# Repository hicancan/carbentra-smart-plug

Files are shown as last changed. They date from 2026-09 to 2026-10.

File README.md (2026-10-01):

<div align="center">

> 2026-10-01 classroom upgrade: the sole multi-device Edge and contract authority moved to `carbentra-campus-platform/edge` and `packages/iot-contract`. This repository owns Plug hardware, firmware and physical qualification facts. New local ON uses the same commissioning/load/feedback/dwell guards; actual presses establish a15-minute manual hold. The default target still disables actuation. Historical broker/PDF evidence does not automatically validate upgraded shared sources.

# CARBENTRA Plug

### 面向校园能源编排的 AIoT 边缘智能插座

**让普通用电设备拥有可感知、可判断、可执行、可验证的能源接口。**

[English](README_EN.md) ·
[机械工程](mechanical/rev_b/) ·
[电气工程](electronics/rev_b/integrated/) ·
[固件](firmware/) ·
[边缘服务](edge/) ·
[发布证据](release/)







</div>

本机数字验证与源码摘要见 [交付入口](release/START_HERE.md)。GitHub 徽章展示远端工作流状态；物理放行条件独立保留。

<p align="center">
  <a href="visuals/rev_b/renders/01_hero_ivory.png">
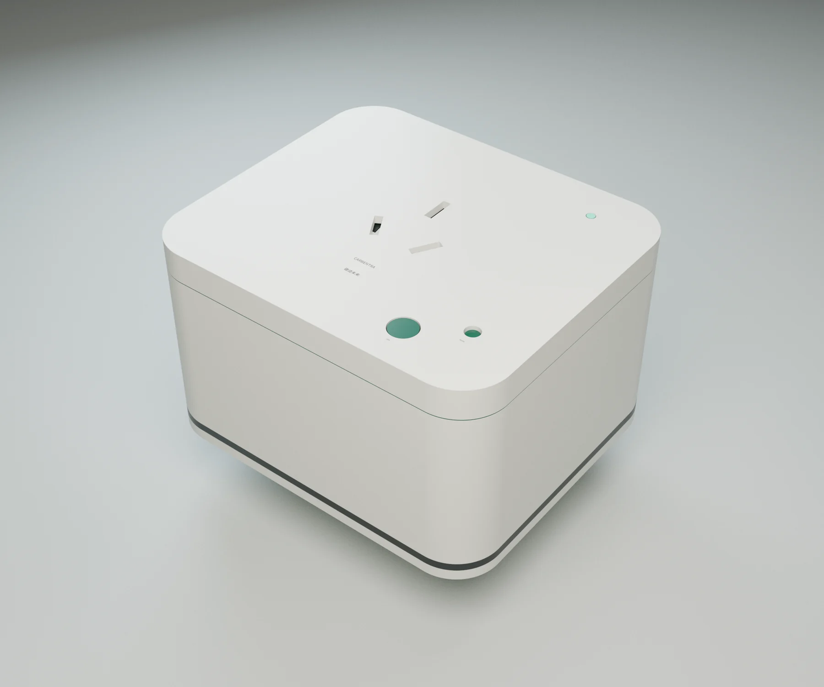
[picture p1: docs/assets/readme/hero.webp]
CARBENTRA Plug Rev B
    
  </a>
</p>

<p align="center">
  <sub>CARBENTRA Plug Rev B · 本地数字验证快照 · 实物尚未验证</sub>
</p>

---

## 一只插座，让普通负载进入可编排能源系统

CARBENTRA Plug 是 CARBENTRA 产品体系的第一个设备终端。

它把传统电器接入一条完整的设备级闭环：

> **感知 → 校验 → 判断 → 执行 → 验证 → 回传**

电压、电流、功率、能量与温度构成设备状态；本地策略决定动作是否具备执行条件；输出反馈确认物理结果；边缘侧持久运输这些事实，平台统一完成资产绑定、预测、约束策略和能碳核算。

当一台设备接入 CARBENTRA Plug，它同时获得联网能力、可观测状态、受约束执行能力，以及一个能够被上层能源系统持续理解的数字接口。

### 四项核心能力

| 能力 | 设备侧职责 |
| --- | --- |
| **感知** | 采集电压、电流、功率、能量、板温与输出状态 |
| **保护** | 本地故障、负载档案、命令时效、序列和物理边界共同参与决策 |
| **执行** | 在本地许可通过后完成受控开关动作 |
| **验证** | 独立读取输出侧状态，把真实结果送回下一轮控制 |

**云端负责全局智能，设备守住物理边界。**

---

## 产品一览

| 项目 | Rev B 数字工程基线 |
| --- | --- |
| 产品名称 | **CARBENTRA Plug** |
| 工程型号 | **CARBENTRA-P16-EVT-B** |
| 名义外形 | **108 × 93 × 65 mm** |
| 主 PCB | **100 × 85 mm，四层** |
| 主控 | **ESP32-C3-WROOM-02U** |
| 电能计量 | **ATM90E26 + 隔离 SPI + 1 mΩ 四端分流器** |
| 机械系统 | **71 个物理机械零件** |
| 主板电气项 | **101 个电气项 + 4 个安装位** |
| 网络链路 | **Wi-Fi + MQTT 双向 TLS** 参考实现 |
| 目标接口 | **单路 220 VAC / 16 A 级设计目标** |
| 当前阶段 | **Rev B 数字工程完成，进入实物 EVT（工程验证样机）前验证阶段** |

<p align="center">
  <a href="visuals/rev_b/renders/02_hero_detail.png">
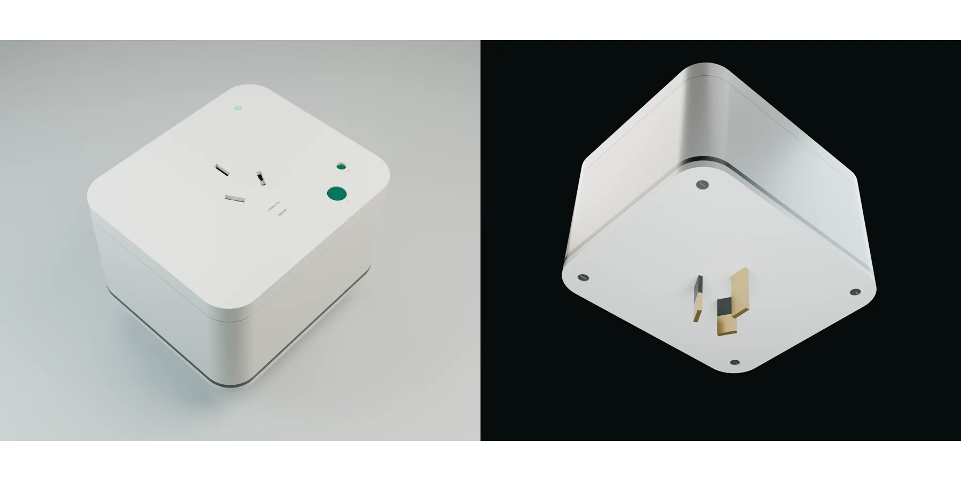
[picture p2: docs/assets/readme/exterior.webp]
CARBENTRA Plug 外观与背部接口
    
  </a>
</p>

外壳、插孔、后部插脚、本地按钮、状态指示、主板空间、保护器件与温度拾取结构都建立在同一套工程坐标系中，并贯通 FreeCAD、KiCad、Blender 与系统装配导出。

---

# 01 · 机械系统 — 让产品在真实空间里成立

Rev B 机械工程覆盖插接结构、保护门、L/N/PE 导电路径、保险与热保护安装、PCB、远端温度拾取、后部插脚和外壳装配。

## 六视图

<a href="visuals/rev_b/renders/07_six_view_sheet.png">
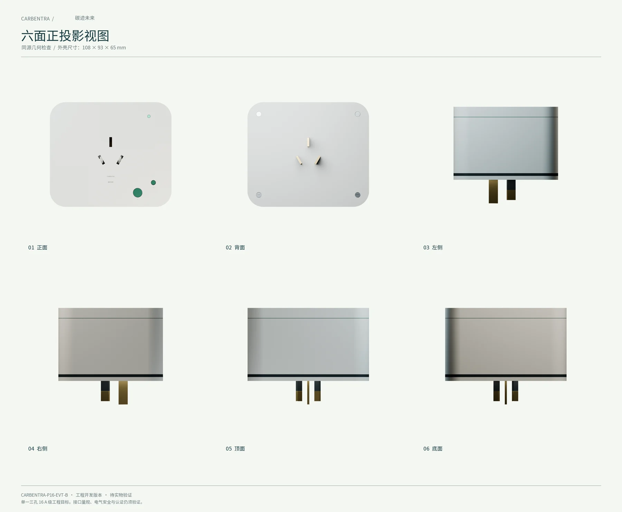
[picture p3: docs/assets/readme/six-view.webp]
CARBENTRA Plug 六视图
  
</a>

六视图给出产品的完整外形关系。当前工程同时提供可编辑 FreeCAD 源、STEP 总装、独立零件、公共坐标系网格、装配边界和机构检查记录。

## 爆炸结构

<a href="visuals/rev_b/renders/06_exploded_annotated.png">
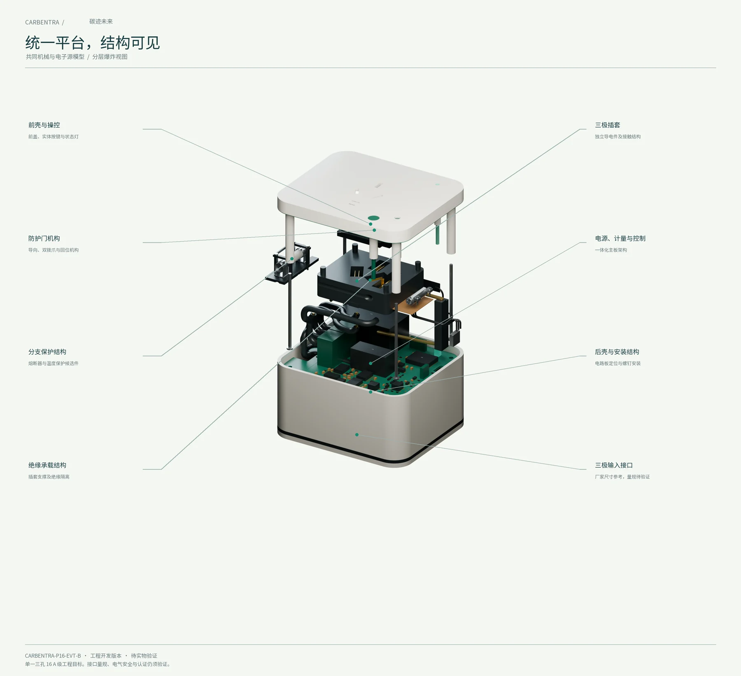
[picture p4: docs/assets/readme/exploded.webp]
CARBENTRA Plug 爆炸结构图
  
</a>

从外到内依次可以看到：

- 前后壳体与装配结构；
- 插孔保护门与接触机构；
- L / N / PE 导电路径；
- 保险与热保护部件；
- 四层主 PCB；
- 远端温度拾取头；
- 后部插脚与内部端接。

### 6 秒爆炸动画

<a href="visuals/rev_b/animation/carbentra_exploded.mp4">
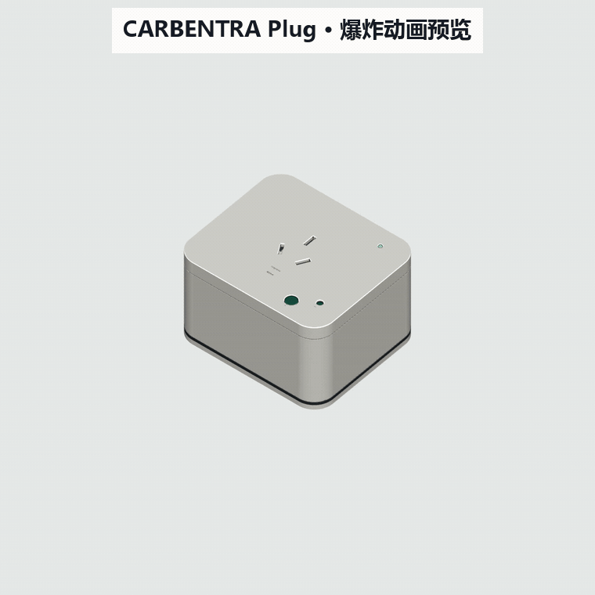
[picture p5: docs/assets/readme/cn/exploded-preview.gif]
CARBENTRA Plug 爆炸动画预览
  
</a>

<p align="center"><sub>点击动画预览可打开原始 MP4。</sub></p>

## 剖视图

<a href="visuals/rev_b/renders/08_section_annotated.png">
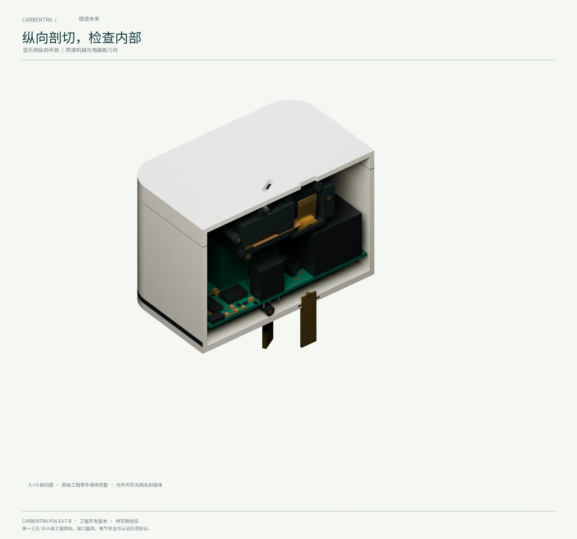
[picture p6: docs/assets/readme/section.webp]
CARBENTRA Plug 剖视图
  
</a>

剖视图展示机械插接结构、电源路径、主板、保护器件与感知部件在封闭体积中的真实相对关系，并与系统总装使用同一坐标基准。

工程源文件：

- [FreeCAD 系统总装](mechanical/rev_b/CARBENTRA-P16-EVT-B_system_assembly.FCStd)
- [机械 STEP](mechanical/rev_b/CARBENTRA-P16-EVT-B_mechanical.step)
- [详细系统 STEP](mechanical/rev_b/CARBENTRA-P16-EVT-B_system_detailed.step)
- [机械验证摘要](mechanical/rev_b/VALIDATION_SUMMARY.md)

---

# 02 · 电气系统 — 把计量、控制、保护与反馈收进同一块主板

CARBENTRA Plug 的电气设计围绕一条明确主线展开：

> **测得准 · 隔得开 · 控得住 · 看得到结果 · 故障时保留本地保护**

<p align="center">
  <a href="docs/assets/readme/cn/electrical-architecture.svg">
    CARBENTRA Plug Rev B 中文电气架构
  </a>
</p>

Rev B 已经整合以下功能域：

- IRM-10-5 隔离 5 V 电源与 AP63203 3.3 V 逻辑电源；
- ESP32-C3 主控、编程接口、本地按钮、状态指示与外置天线接口；
- ATM90E26 电能计量链路、1 mΩ 四端分流器与隔离 SPI；
- 输出侧 AC presence 独立反馈；
- 远端 TMP302 温度阈值链路、锁存与本地物理复位；
- 主保险、热保护、继电器与输出路径；
- 连续 PE 保护导体路径。

## 原理图

<a href="electronics/rev_b/integrated/exports/schematic.pdf">
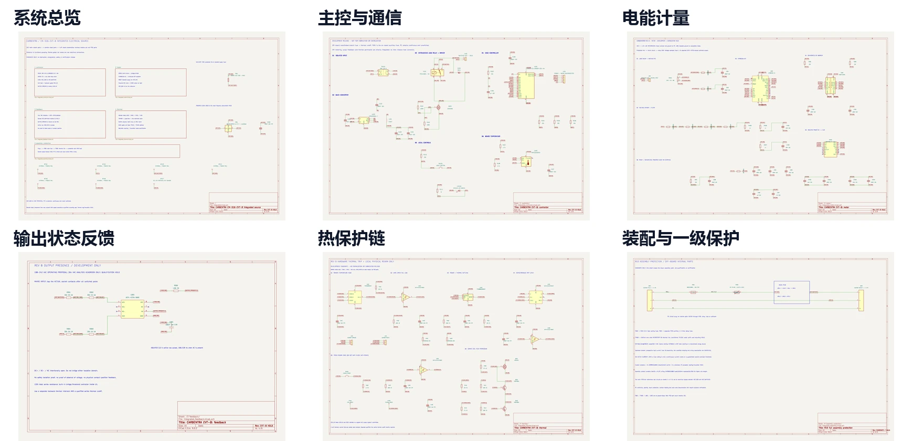
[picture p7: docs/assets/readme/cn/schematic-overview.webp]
CARBENTRA Plug Rev B 六页原理图总览
  
</a>

**点击上图打开完整原理图 PDF。**

README 总览采用中文功能页名称；元件位号、网络名与工程信号名保留 KiCad 原始命名，方便直接对应设计源文件。

六个功能页面：

[系统总览](electronics/rev_b/integrated/exports/integrated.svg) ·
[主控与通信](electronics/rev_b/integrated/exports/integrated-1%20controller.svg) ·
[电能计量](electronics/rev_b/integrated/exports/integrated-2%20meter.svg) ·
[输出状态反馈](electronics/rev_b/integrated/exports/integrated-3%20feedback.svg) ·
[热保护链](electronics/rev_b/integrated/exports/integrated-4%20thermal.svg) ·
[装配与一级保护](electronics/rev_b/integrated/exports/integrated-5%20assembly%20protection.svg)

KiCad 原生工程：

[`electronics/rev_b/integrated/`](electronics/rev_b/integrated/)

## 四层 PCB

Rev B 主板采用 **100 × 85 mm 四层设计**。当前数字检查记录：

- DRC 违规：**0**
- 未连接项：**0**
- 封装错误：**0**
- ERC 错误 / 警告：**0 / 0**
- 原理图—PCB 独立引脚键对照：**321 / 321 一致**

<a href="electronics/rev_b/integrated/exports/copper_review.pdf">
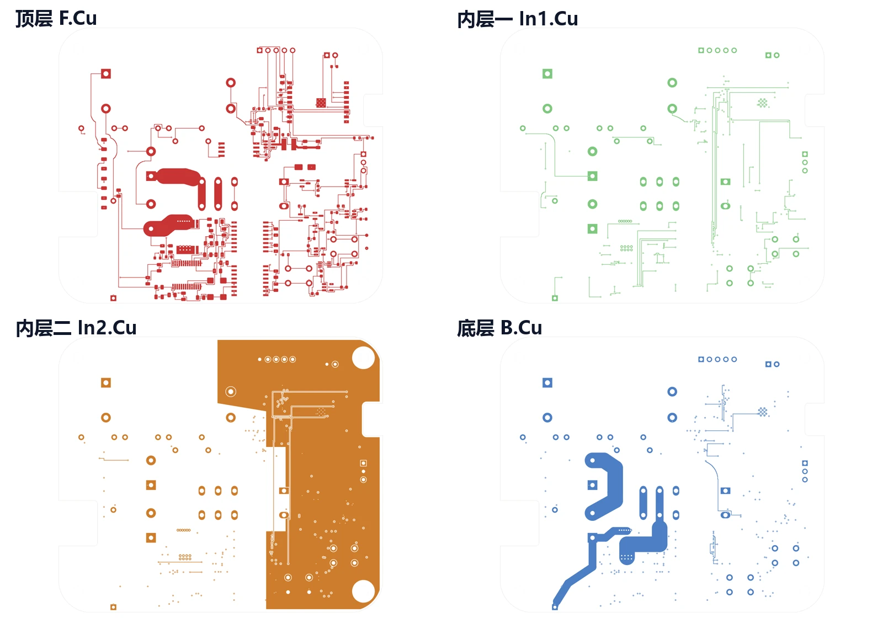
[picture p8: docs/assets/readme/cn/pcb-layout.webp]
CARBENTRA Plug 四层 PCB 铜层总览
  
</a>

上图按照 **顶层 F.Cu / 内层一 In1.Cu / 内层二 In2.Cu / 底层 B.Cu** 展示当前铜层。点击可打开完整铜层审阅 PDF。

## PCB 装配

<a href="visuals/rev_b/renders/09_pcb_annotated.png">
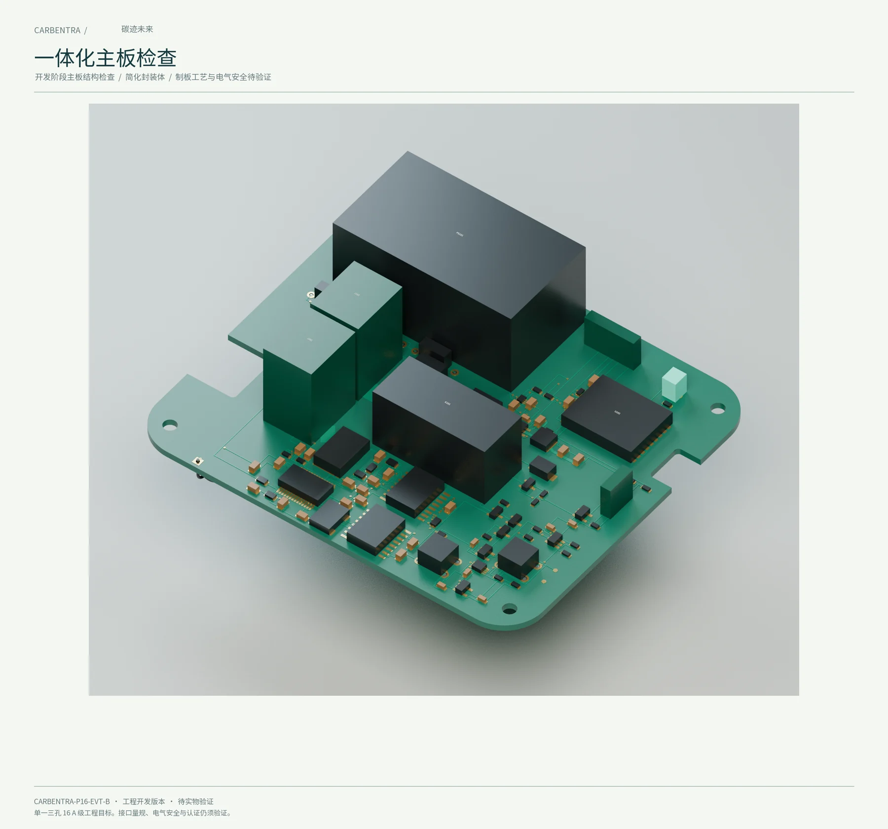
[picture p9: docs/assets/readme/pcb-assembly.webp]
CARBENTRA Plug PCB 装配
  
</a>

PCB 视觉装配直接由当前 ECAD 导出进入机械总装与 Blender 展示场景，实现原理图、PCB、机械结构和视觉资产之间的连续追踪。

进一步查看：

- [KiCad 原生工程](electronics/rev_b/integrated/integrated.kicad_pro)
- [电气 BOM](electronics/rev_b/integrated/electrical_bom.csv)
- [电气设计定义](electronics/rev_b/integrated/ELECTRICAL_SOURCE.md)
- [功率与电流复核](electronics/rev_b/integrated/POWER_CURRENT_REVIEW.md)
- [最终电气验证摘要](electronics/rev_b/integrated/validation/final_summary.json)

---

# 03 · 固件控制 — 把每一次物理动作放进本地安全上下文

CARBENTRA Plug 会在设备端重新判断每一条控制请求。

CARBENTRA Plug 中文固件控制链

控制链依次检查：

- 设备身份与目标；
- 命令时间边界与 TTL；
- 命令序列与重放；
- 当前负载档案；
- 本地故障锁存；
- 计量数据有效性；
- 动作间隔与当前物理状态；
- 输出反馈与请求状态的一致性。

### 三条核心原则

1. **本地安全拥有最高执行优先级。**
2. **过期、重放、错目标和异常格式命令直接拒绝。**
3. **未知或未批准负载进入仅监测状态。**

当前固件代码已经覆盖：

- C 策略核心；
- ATM90E26 采集与完整性检查；
- TMP102 板温采集；
- AC presence 边沿反馈；
- Wi-Fi 重连；
- BLE 安全配网路径；
- MQTT 双向 TLS；
- retained 消息、分片、长度、类型与重复键边界检查；
- NVS 持久命令序号；
- 有界 RAM 遥测缓冲；
- 边缘侧持久化回执语义。

## 可复现软件检查

```powershell
uv venv --python 3.12
uv sync --locked
$env:CARBENTRA_PLATFORM_ROOT='D:\code\github\hicancan\carbentra-suite\carbentra-campus-platform'
pwsh -NoProfile -File scripts/check_windows.ps1 -OutputDirectory 'D:\Temp\codex\carbentra-plug-check' -BuildTarget
```

本机环境、原生 CAD 重建顺序与工具路径见 [Windows 开发说明](docs/WINDOWS_DEVELOPMENT.md)。

Windows 入口会自动编译真实 Switch C 解码器，并将它与三个 Plug C 验证器
一起传入共享 Edge 的 `--release` 门禁。默认从同级的共享平台及 Switch 仓取源；
不同目录可传 `-PlatformRoot`、`-SwitchRoot`。编译入口是共享平台的
`edge/tests/c/switch_command_decoder.c`，链接 Switch 的
`firmware/core/switch_core.c`、`firmware/main/command_json.c` 与 SDK 固定版本
cJSON，构建记录保存源文件及程序 SHA-256。该程序只解析命令行 JSON，
退出码 0/1 分别表示接受/拒绝，没有设备或网络操作。需要复用已编译程序时，
仍可显式传 `-SwitchCommandTestBinary`；缺失或失败不会降级为跳过。
Linux `run_development_checks.sh` 和独立完整 release 验证器仍要求
`CARBENTRA_SWITCH_COMMAND_TEST_BINARY`。CAD 或场景改变时，再加
`-CheckNativeCAD -RenderGPU`；Windows 通过不会自动更新历史 Linux/CAD 证明。

[本次固件复验](firmware/remediation-report.json)记录全新 ESP-IDF 5.4.3 目标构建、
host 安全回归和新增共享解码器门禁的传递检查。它不修改原有实物 HOLD 状态，
也不把历史 CAD/制造报告重新标为本次运行。

当前仓库已验证：

- 唯一 C 本地保护核心，**45** 个策略用例；
- 边缘发布门禁记录 OS 专属排除与互补验证，当前测试数量见 firmware/evidence/shared-edge-validation.json；
- **10,000** 次本地故障优先级不变量检查；
- 协议 / 计量复位 / 链路卡滞回归；
- 输出反馈判定测试；
- 已配置 GitHub Actions Windows 主机门禁和 ESP32-C3 目标构建；远端执行状态以 Actions 记录为准。

ESP32-C3 当前源码已使用官方 ESP-IDF 5.4.3 重新构建，默认继电器禁用、证书有效期校验启用；源码与产物摘要见 firmware/validation.json。真实硬件验证仍为 HOLD。

---

# 04 · 边缘协同 — 把设备事实沉淀成楼宇侧状态

设备把测量与执行结果交给边缘节点，边缘节点将它们组织成可以持续协调的楼宇侧状态。

共享平台仓库中的边缘服务提供：

- MQTT 设备适配；
- 允许清单与设备身份校验；
- SQLite WAL 持久化；
- 启动纪元 + 序号去重；
- 持久化回执；
- 控制回执保存；
- 带重试和冲突隔离的 HTTP outbox；
- 持久命令 inbox、租约、过期/重放守卫和独立物理放行门；
- 源摘要绑定的真实软件 broker / 平台联调。预测、调度和核算只有平台一份实现。

一条设备遥测在成功落库后返回持久化回执，由此可以清晰区分“消息已到达 MQTT 消息代理”和“数据已进入边缘状态库”。

[查看边缘参考服务](edge/README.md)

---

# 05 · 云边端协同 — 从一个设备节点扩展到一组可协调负载

当设备端的感知、执行和反馈闭环成立，多台 CARBENTRA Plug 就可以进入更高层的能源协调。

CARBENTRA 云边端协同架构

系统分工：

- **CARBENTRA Plug**：感知、保护、执行、验证；
- **CARBENTRA Edge**：合同校验、持久收据、重试运输、命令网关；
- **CARBENTRA Cloud**：负荷预测、约束策略评估、全局调度；
- **CARBENTRA Twin**：映射设备、空间、能耗、碳排与执行状态。

> **一只 Plug 让一台设备可被控制；一组 Plug 让一片负载可以被协同。**

CARBENTRA Plug 位于能源算法与真实物理设备之间，把调度策略落到最后一米，并把执行结果重新送回系统。

---

## 工程进度

| 领域 | 当前状态 |
| --- | --- |
| 产品定义 | ✅ CARBENTRA Plug Rev B 数字基线 |
| 机械 CAD | ✅ 原生 CAD + STEP + 装配 / 机构 / 连通性证据 |
| 电气设计 | ✅ 六页原理图 + 四层 PCB + ERC / DRC 数字检查 |
| 固件主机逻辑 | ✅ 策略、协议、反馈、计量回归测试 |
| 边缘参考服务 | ✅ 严格合同、持久运输、mTLS 虚拟设备闭环 |
| 视觉 / 数字孪生资产 | ✅ Blender、GLB、渲染、爆炸动画 |
| ESP32-C3 新版目标二进制 | ✅ 官方 ESP-IDF 5.4.3 当前源码实际构建，继电器禁用 |
| 实物 EVT（工程验证样机） | ⏳ 下一阶段 |
| 逐台计量标定 | ⏳ 实物阶段 |
| 16 A 温升 / 故障验证 | ⏳ 实物阶段 |
| 绝缘 / EMC / 浪涌 / 安规 | ⏳ 专业审查与试验阶段 |
| 校园现场闭环 | ⏳ EVT 与安全放行后进入 |

完整工程放行条件：

[`docs/ENGINEERING_RELEASE_GATES.md`](docs/ENGINEERING_RELEASE_GATES.md)

---

## 打开工程

### 机械工程

```text
mechanical/rev_b/
├── CARBENTRA-P16-EVT-B.FCStd
├── CARBENTRA-P16-EVT-B_mechanical.step
├── CARBENTRA-P16-EVT-B_system_assembly.FCStd
├── CARBENTRA-P16-EVT-B_system_assembly.step
├── CARBENTRA-P16-EVT-B_system_detailed.step
├── parts/
├── meshes/
└── validation reports...
```

### 电气工程

```text
electronics/rev_b/integrated/
├── integrated.kicad_pro
├── integrated.kicad_sch
├── integrated.kicad_pcb
├── electrical_bom.csv
├── electrical_manifest.json
├── exports/
└── validation/
```

### 固件与边缘服务

```text
firmware/
├── core/
├── main/
├── tests/
├── tools/
└── validation.json

edge/
├── README.md        # shared implementation: carbentra-campus-platform/edge
└── PROVENANCE.json  # migration record
```

### 视觉与数字孪生

```text
visuals/rev_b/
├── carbentra_studio.blend
├── carbentra_animation.blend
├── exports/
│   ├── carbentra_assembly.glb
│   └── carbentra_twin_light.glb
├── renders/
└── animation/
```

---

## 仓库结构

```text
carbentra-smart-plug/
├── mechanical/      # CAD、STEP、零件、机构与装配检查
├── electronics/     # KiCad 原理图、PCB、BOM、电气验证
├── firmware/        # ESP32-C3 源码、策略、计量、网络与主机测试
├── edge/            # 平台共享 Edge 的迁移说明与来源记录
├── visuals/         # Blender、渲染、GLB、动画
├── docs/            # 系统契约、品牌体系与平台叙事
├── tests/           # 策略参考测试
├── scripts/         # 验证与发布工具
└── release/         # 数字工程发布证据与审阅材料
```

按照工程审阅顺序阅读时，可以从 [`release/START_HERE.md`](release/START_HERE.md) 开始。

---

## 从数字工程走向实物 EVT

当前 Rev B 已经把机械、电气、固件、边缘服务和视觉资产收敛到同一套数字工程基线。下一阶段将把这些设计结论逐项落到实物验证：

- 目标市场对应的插头 / 插座标准确认；
- 实际爬电距离、空气间隙与绝缘结构审核；
- 外壳材料与异常工况验证；
- 预期故障电流与保护配合；
- 16 A 封闭温升与连接点发热试验；
- 插接量规、接触力、寿命、保持力与保护门验证；
- 不同负载类型的浪涌与继电器开断能力测试；
- 电压、电流、功率、能量逐台可溯源标定；
- 浪涌 / EFT / EMC / RF 集成测试；
- 生产级设备身份、安全启动、升级与密钥配置；
- 受控实物 EVT 与真实场景闭环验证。

> [!WARNING]
> **220 VAC / 16 A 级接口目前属于设计目标。实物额定能力、制造放行与产品合规将在上述验证完成后确定。**

---

## 项目与品牌

**CARBENTRA Plug** 是 CARBENTRA 产品体系中的首个设备终端。

```text
碳迹未来
└── CARBENTRA
    ├── CARBENTRA Plug      ← 本仓库
    ├── CARBENTRA Sense
    ├── CARBENTRA Edge
    ├── CARBENTRA Cloud
    └── CARBENTRA Twin
```

比赛 / 项目名称：

> **碳迹未来——基于 AIoT 云边端协同的高校智慧能碳管理平台**

平台英文描述：

> **CARBENTRA — AIoT Campus Energy Orchestration Platform**

完整平台叙事：

[**docs/PLATFORM_OVERVIEW.md**](docs/PLATFORM_OVERVIEW.md)

---

<div align="center">

# CARBENTRA Plug

### **Sense · Protect · Execute · Verify**

**让普通设备进入可编排的能源系统。**

[English README](README_EN.md)

</div>

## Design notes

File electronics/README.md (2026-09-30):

# CARBENTRA electronic development release

## What exists

Editable KiCad 9 schematic and two-layer 72×68 mm PCB; upstream-symbol-derived pin geometry; 33 placed electrical components plus 4 mounting holes (37 footprints); real net assignments; fully connected isolated low-voltage routing (digital connectivity only); true KiCad ERC/DRC reports; BOM candidate sources; board/package STEP, FreeCAD and OBJ; regenerated PDF/SVG review drawings. This is a **development source release with FABRICATION HOLD**, not a finished appliance circuit or a safe prototype to energize.

Main controller: ESP32-C3-WROOM-02U-N4 with external antenna connector, 5 V isolated supply candidate, 3.3 V synchronous buck, relay MOSFET/flyback network and digital board temperature sensor, physical local pushbutton and status LED. GPIO 18/19 are allocated to these controls, so native USB is not available on this revision. Main switching candidate is TE RT314005 5 V coil. Mains input/output/fused-auxiliary nets are intentionally unrouted. The right-hand LV routing region is digitally connected and DRC-checked, not a verified EMC/power integrity layout.

A real external antenna candidate and a mechanical pocket are defined in `PROTECTION_AND_RF.md`. Check module integration approvals and qualify range with enclosure/contact metal. The MCU variant is 02U, with an external antenna.

## Files

- `carbentra.kicad_sch`, `.kicad_pcb`, `.kicad_pro`, `.kicad_dru`: editable source and preliminary constraints
- `CARBENTRA.kicad_sym`, `sym-lib-table`: local symbols, flattened from installed KiCad library for portability
- `circuit_manifest.json`: machine-readable pins, nets, placements and schematic positions
- `bom.csv`: candidates, NOT a purchase-approved BOM; passives require precise grade/voltage/package selection
- `METERING_DESIGN.md`: substantive isolated metering boundary, pin map and sizing; daughterboard NOT implemented
- `validation/`: actual ERC, DRC, routing and geometric validation outputs
- `exports/`: review-only models/drawings
- `scripts/build_electronics.py`: regenerate source (overwrites board routing)
- `scripts/route_lv.py`: attempt LV routing, always follow with real DRC
- `scripts/export_geometry.py`: nominal package envelopes + board/footprint pad visualization

## Functional and power assumptions

IRM-03-5 candidate supplies 5 V/0.6 A. A 0.403 W relay coil consumes about 81 mA. An assumed 0.5 A peak 3.3 V controller load at 85% buck efficiency draws 388 mA from 5 V, leaving about 131 mA before other loads and supply derating. This is a preliminary budget, not measured. Include metering isolation power and all transients before final selection; verify rail dips during simultaneous radio transmission/relay actuation. Buck capacitor effective capacitance must account for DC bias, and high-current loop/switch-node layout requires review.

AP63203 pins: 1 FB → 3.3 V; 2 EN → 5 V; 3 IN → 5 V; 4 GND; 5 SW; 6 BST. Q1 is AO3400A, with manufacturer maximum RDS(on) of 48 mΩ at 2.5 V gate drive. Its pins are 1 gate, 2 source to ground, 3 drain to coil-low. D1 cathode connects to 5 V and anode to coil-low. R2 holds the gate low when the MCU is high-impedance; it is not an independent safety channel. Relay contact 11 is common, 14 is normally open, and 12 is externally unused but remains a hazardous live terminal when the relay is de-energized; it is assigned L_NC_UNUSED for clearance checking. A welded contact cannot be made safe by firmware.

Cold boot / loss of control power de-energizes this monostable relay. Runtime unknown-load handling is monitor-only; stale data rejects new automatic commands and holds the commissioned state, as specified in the system reference model. Hardware fault interruption, watchdog policy and power-restoration behavior must be commissioned by load category. This board does not implement a universal abrupt shutdown policy.

## Mains and PE

Target: 220 V nominal, 16 A-class single polarized socket. Actual continuous current, branch protection, terminal rating, contact category and operating temperature remain unqualified. **16 A resistive relay rating does not establish air-conditioner/compressor/motor, transformer or capacitive-inrush capability.** Profile software cannot uprate contacts or copper. Unknown loads are monitor-only for automatic energy management; known load categories still require validated hardware limits.

J1, J2 and J5 use Phoenix MKDS 3/2-5.08, part 1711725, with the matching KiCad footprint. Its 24 A nominal rating is a component rating, not this product's released continuous-current rating. Confirm the final conductor, torque, support, temperature rise and strain relief. High-current copper is absent: copper weight, width, neck-downs, solder joints and fault let-through must be engineered before routing. Do not bridge the airwires and energize.

Real main/auxiliary fuse and independent thermal-cutoff candidates are now dimensioned in `PROTECTION_AND_RF.md` and allocated mechanically; their electrical/harness integration and coordination are not validated. Surge network and any required snubber remain incomplete. They require ratings, layout, failure-mode analysis and system-level testing. A fuse is not an over-temperature sensor; a MOV alone is not complete surge protection.

PE bypasses this PCB in an uninterrupted stamped/wired protective path and must never be switched, fused or routed through the MCU ground. Mechanical PE continuity solids are not proof of actual earth-bond resistance, retention or contact force. Never assume N is safe to touch; polarity/reversal fault analysis and all-pole disconnection requirements depend on final product category.

## Review gates before any hardware build

- [ ] Choose target jurisdiction, plug/socket dimensional standard, accessible-part class, temperature range and required compliance tests
- [ ] Complete all mains/protection/metrology circuits and independent thermal safety; produce fault tree and critical-component list
- [ ] Resolve all KiCad unconnected nets and DRC violations without suppressing safety failures
- [ ] Verify every manufacturer pin/footprint drawing, exact suffix, BOM source and symbol connectivity independently
- [ ] Confirm required clearance/creepage from applicable standards; 8 mm rule is an explicitly preliminary engineering target, not a compliance conclusion
- [ ] Validate all copper currents/temperature rises, conductor/terminal retention, PE bond and short-circuit withstand
- [ ] Complete external antenna and metering daughterboard mechanical allocations, wiring paths, connectors and controls
- [ ] Test surge/EFT/ESD/EMI, dielectric/impulse, leakage, abnormal temperature, relay endurance and welded-contact behavior in a qualified lab
- [ ] Verify watchdog, brownout, cold-boot de-energization, stale-data command rejection, offline commissioned-state hold and secure signed firmware behavior
- [ ] Release only after independent electrical/safety review and documented manufacturer acceptance

No Gerber/drill set is supplied because it would misleadingly imply fabrication readiness. Reports may be clean in one domain while the design remains incomplete and unsafe to power.

## Final digital verification

ERC: **0 errors, 0 warnings**. PCB DRC: **0 geometric violations**, **0 low-voltage airwires**, **9 intentional mains-domain airwires**. All 104 assigned pins match the exported schematic netlist and PCB pads. See `validation/final_summary.json` and the complete, unfiltered reports. DRC success does not remove fabrication hold: the mains circuit remains physically incomplete and the metering daughterboard is not implemented.

The final board has 729 routed segments, 85 vias and 2 ground zones. These establish digital connectivity, not safe current capacity, EMC performance, transient integrity, or protection behavior. No embedded firmware has been flashed or exercised on hardware.

KiCad library symbol geometry is attributed to the KiCad Community under its library licence and design exception; see `KICAD_LIBRARY_LICENSE.txt`.

## Rebuild and system interfaces

Run `bash scripts/rebuild.sh` with KiCad 9 and its Python bindings installed. It regenerates placement and schematic, checks fixed geometry, then replays the reviewed completed-LV copper recipe. Do not rerun the experimental autorouting helpers on the finished board. Exporting package STEP/OBJ also requires FreeCAD Python; `scripts/export_geometry.py` handles it.

For the Wi-Fi/BLE deployment boundary, sensor ownership and exact runtime unknown/stale-data behavior, see [wireless networking and sensors](../docs/system/network-and-sensors.md) and [system requirements](../docs/system/README.md). The PCB includes board temperature sensing, not a complete hot-contact telemetry path. Independent relay/output-state feedback and the metering daughterboard remain incomplete.

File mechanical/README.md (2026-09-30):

# 碳迹未来 CARBENTRA-P16 · 机械工程开发模型

**版本 CARBENTRA-P16-EVT-A。工程开发设计，禁止按此直接制造通电样机。**

这是一个统一硬件平台：单个三孔、16 A 等级、220 VAC 设计目标，软件负载能力档案不改变插头/插座的物理兼容性。没有 10 A 插头兼容性或“万能孔”承诺。不是米家产品内部复原。六张用户参考图片仅用于观察外观类别；所有内部结构和尺寸是本项目自定义设计输入。

## 文件与打开方式

- `CARBENTRA-P16-SystemAssembly.FCStd` / `.step`：统一坐标的完整机械+KiCad板件装配（电子器件为候选包络）
- `CARBENTRA-P16-EVT-A.FCStd`：54 个独立、命名、可检查的 FreeCAD 实体与参数表
- `CARBENTRA-P16-EVT-A.step`：装配交换文件
- `step/*.step`：单件 STEP；`meshes/*.stl`：对应单件可视化网格
- `design_parameters.json`：尺寸、坐标、接口和工程边界
- `parts_manifest.json`：部件清单、材质候选、色彩、包围盒与建议爆炸位移
- `drawings/CARBENTRA-P16-EVT-A_general_arrangement.pdf` / `.svg`：A3 总体尺寸与装配控制图；侧向视图是标明的名义堆叠布局，不是隐藏线投影的制造剖面
- `validation.json`：54 个机械实体的逐对 BRep 干涉审计
- `integration_validation.json`：FCStd 重载、参数编辑、PE 联通、PCB/元件包络适配审计

FreeCAD 1.0.0 已验证。通过 FreeCAD 宏面板打开 `Open_Model.FCMacro`，它设置本地参数模块搜索路径、打开源文件并应用材质色。直接打开 FCStd 可查看保存的实体；若要重算 Python 参数特征，应先将本目录加入 Python 路径并导入 `socket_features`。外部 Python 代理源码随项目提供，无插件下载。

在本机已安装环境重建：

```sh
/usr/bin/python3 mechanical/generate_model.py
/usr/bin/python3 mechanical/validate_assembly.py
/usr/bin/python3 mechanical/drawings/generate_drawing.py
```

FreeCAD 的 Parameters 表格 B1/B2/B3 驱动 Width/Height/Depth。已实测宽度 88→90→88 的原生重算。JSON 包含其余设计输入；更改后重运行生成器。尺寸系统是受约束的开发模型，任意大幅改尺寸后必须重新检查干涉和接口，不是无限适配的插座生成器。

## 坐标与结构

单位 mm。原点为后壳中心的背面 z=0；+Z 为插座正面，+Y 指向 PE 插孔。

| 项目 | 名义值 |
|---|---|
| 外壳 | 88×88×55；平面角半径14 |
| 后向插脚伸出 | 20（待标准量规替换） |
| 壁厚/背板 | 2.4 / 3 |
| 前后壳分界 | z46；前盖正面 z55 |
| PCB | 72×68×1.6；z8–9.6；元件上限 z28 |
| PCB 安装孔 | D3.2，(±31,±29) |
| 接触件绝缘载体 | 主体 z31–47；上部压紧凸台至52.6 |
| 后侧装配螺钉轴 | (±38,±24) |
| 正面按键/导光柱 | (0,-32)/(0,33) |

后壳包含 PCB 支柱和 z30–31 的侧向载体承台。载体被前盖的接触面与承台夹持，上下包络不穿过 PCB。四个后侧长螺钉连接前盖盲孔柱；螺纹、扭矩、拉拔力及防触及要求待专业设计。实际制造需要定位止口、拔模与公差链，不应直接以理想面接触替代制造间隙。

三个接触件放在各自绝缘腔中，接触底面与腔底 z34 对齐。其几何是接触簧片包络，不代表经过材料、接触力或耐久试验的合格簧片。前盖三孔与后插脚坐标一致，但孔宽/角度/间距/片厚均为**临时设计值**，不得当成中国 16 A 标准尺寸使用；须以有效标准和匹配的合格采购件更新。

## 电气连接与真实完成边界

PE 插脚→PEBus→PE 插套的几何并集为一个有效实体。该路径绕过 PCB 右侧，不经过继电器或计量开关。两个导电接口采用少量有意重叠来表示连接。它证明的是 CAD 连通，不证明焊接/铆接工艺、接地电阻或保护导体故障电流承受能力。PE 导体绝缘、固定、爬电与电气间隙仍需设计验证。

L/N 插脚与插套已加入分开的导体/绝缘护套路径，载体中有两个 D3.0 馈线通孔；端点对应电子板 J1/J2。护套外径2.8、导体直径1.3仅用于布线空间研究，**不是16 A线径选择**，也不代表导体载流量、弯曲半径、绝缘温度等级或端接的放行。导体在端子简化包络中有六处预期接入，实际进线孔与夹紧结构未确定。

已把保护组件真实分配到外壳内部，原先的保护断开空间已关闭。主通路按 L插脚→F_MAIN→TF1→保护后分支，分别供给J1与F_AUX→J5。N插脚分别连至J1/J5，负载N通过板端接口延续；PE独立连续。

- 左前口袋：Schurter OGN0031.8201开式保险丝座，主体包络25×9.6×11.5、引脚距22.5；配Littelfuse0216016.MXP 16A快断5×20陶瓷保险丝。独立壳内小托台与引脚通孔已建模
- 右前口袋：SensienceMICROTEMP G5系列热切断器，主体D4×14.7；110°C候选须根据真实接触件、壳体、热梯度重新确定。固定夹、热耦合与最终订货型号仍待确认
- 上部托台：Littelfuse0215001.MXEP 1A慢断轴向辅助保险丝，21.5×D5.5包络。长供货引脚按三维布线包络截短表示，端接与弯曲工艺未放行
- OGN无盖16A名义条件不能直接当成本封闭外壳内的持续16A能力；盖子会降低额定能力。全部保护器件仍须核算降额、短路分断、PSU浪涌I²t及相互配合

供应商来源与电气选择边界见电子目录的PROTECTION_AND_RF.md。器件外形按已核实包络简化建模，保险丝座内部金属夹、端接结构、热熔断器安装与陶瓷内部熔体不是供应商精确内部复原。

按键现有偏置推杆下端与电子板SW1(0,-29,z13.9)顶面匹配，正面按键仍为(0,-32)；导光柱延伸到LED1(0,31,z14.9)，正面出光点仍为(0,33,z55)。已做共同坐标包络检查；长推杆抗弯、行程/回弹/导向、光导耦合效率与安装公差尚未验证，不能把几何接触当成量产机构。

`ShutterSlider` 与 `ShutterGuide` 仅为联动防护门结构空间研究。弹簧、复位、双插脚同时触发、插拔运动、防单极插入及探针试验未实现或验证。不得宣称已有合格儿童保护门。

## 验证记录与放行门槛

脚本检查：所有 54 个机械形体有效且各自单实体；机械两两交集仅允许清单中明确列出的导电接合、保险丝端帽/引脚、线束分支绝缘拼接与天线馈线接口。对 72×68 PCB 与电子组提供的33个元件包络做共同坐标检查，六处端子接入已明确分类为预期界面。每次电子布局更改须重新运行整合审计。简化元件包络检查不等于供应商精确 3D 模型检查。

本包不包含：标准符合性、完整爬电/电气间隙矩阵、温升/故障试验、插拔力与接触电阻、模具可制造性、阻燃认证、跌落/冲击、额定负载切换与寿命、耐压、EMC、产品认证或通电许可。用户界面的“16 A”必须注明设计目标，不能替代产品合规铭牌。

下一步必须先选择标准化合格插接组件与匹配继电器/端子，完成线束及隔离、详细公差/热设计，再由合格人员评审低压样件和电气试验计划。

### 标准核查目标

插接尺寸应按现行强制性 [GB 1002-2024](https://openstd.samr.gov.cn/bzgk/std/newGbInfo?hcno=F8C9E208891B7BB5AF1B3E64933693C2) 核查。已核实其于2025-08-01实施并替代GB/T 1002-2021；本次未取得标准尺寸图或完成量规比对，不能把临时CAD数值视为合标。

## 外置射频天线

Taoglas FXP73.07.0100A柔性天线按47×7×0.1mm位于上内壁，独立100mm长、1.13mm外径同轴布线包络含平面松弛盘绕。RF模块端点仅匹配ESP32-C3-WROOM-02U的模块空间，精确MHF I/U.FL插座位置尚无供应商3D坐标，未声称精确连接器轴线。天线效率、近金属禁布区、同轴最小弯曲半径、模块许可天线增益列表与整机EMC测试均未验证。天线和线缆尺寸来源：https://www.taoglas.com/datasheets/FXP73.07.0100A.pdf

## 插入通道校核

新增三孔的临时插脚扫掠空间检查：2.0×6.8mm矩形截面，z35.5至55.5，跟随各孔角度。这是发现线束挡住插孔的几何测试，不是标准量规。仅闭合的L/N保护门允许与该空间相交；PE通道与所有线束应无交集。试验数据列于integration_validation.json。

### 当前终端坐标（共同坐标，mm）

已匹配Phoenix Contact MKDS3/2-5.08（1711725）的已选包络，安装高度18mm、板顶z9.6，端子顶面z27.6：J1两位(-26,-9.5)/(-20.92,-9.5)，J2两位(-22,-26)/(-16.92,-26)，J5两位(-18,28)/(-12.92,28)。这些是顶面布线入口表示；实际夹持/进线轴线未替代供应商装配图。

主线导体/护套包络半径0.65/1.4mm，辅助线0.325/1.0mm。数值服务于初始装配检查，不是符合16A载流量或绝缘等级的选择；真实线材选择可能要求重新布线或增加外壳空间。部分理想几何间隙低于1mm，尚无公差链和完整电气间隙评审，严禁把“零实体交叠”当作安全间距通过。

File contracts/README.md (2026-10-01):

# Plug wire boundary notes (shared contract authority)

The sole schema and semantic authority is now `carbentra-campus-platform/packages/iot-contract`, including `schemas/wire/`, `python/carbentra_iot_contract/plug_wire.py` and canonical examples. No schema is vendored or independently maintained here. The hardware-specific `device-capabilities.json` documents physical interfaces and release limits, with an explicit shared descriptor reference.

Topic routing remains `carbentra/v1/{device_id}/{hello,time,telemetry,receipt,cmd,ack}`. The wire payload remains v2 with additive local-input/manual-hold fields. Real firmware JSON encoding is compiled through host drivers and checked against the shared package by the platform Edge integration suite.

## Identity, units and evidence

`(device_id, boot_epoch, sample_seq)` is the immutable telemetry key. `sample_seq` is a canonical decimal string in 1..18446744073709551615, never a JavaScript number. The same key with different content is a conflict, not an update. An authenticated server derives receipt time; client time never replaces it.

Power is W; forward/reverse accumulated known energy is Wh since this boot. Never sum cumulative Wh, never relabel it kWh, never compare across boot epochs. The platform computes qualified adjacent deltas and converts Wh→kWh once; gaps, reverse flow, coverage, missing data and meter topology remain explicit. Counters or inferred savings do not make an uncalibrated sample usable.

`monotonic_ms` is the snapshot capture time; `measurement_monotonic_ms` is its last measurement. Feedback and board temperature are distinct observations; board temperature is not room or contact temperature. Optical absence of pulses never proves safe voltage absence.

Authenticated sample time is an interval: `unix_lower_s <= unix_s <= unix_upper_s`, width at most 5 seconds. Every value comes from the same current authenticated MQTT challenge/monotonic anchor at capture. Unknown time has `time_quality: unknown` and all three unix values null. Buffered retransmission never re-times or mutates a snapshot. The platform can display receipt-time fallback, but must exclude uncertain time from calendar allocation, forecasts and accounting.

Periodic telemetry carries `fault_latched`; a newly latched fault immediately adds a sample even without any new command. Offline is derived by the platform from received time/freshness, independently from electrical output state.

## Command outcomes

`REQUESTED_AWAITING_FEEDBACK` and `ACCEPTED_NO_CHANGE` are nonterminal. Even no-change commands wait for a fresh qualified observation. One execution can await feedback at a time; a new command is rejected as `BUSY_AWAITING_FEEDBACK`. The local five-second observation deadline never extends because of retries or connectivity.

Terminal outcomes include `OBSERVED_VERIFIED`, `FAILED_FEEDBACK`, `FAILED_SUPERSEDED`, and `TIMED_OUT`. They contain the same command ID/sequence, boot epoch, requested/deadline/observed monotonic times and actual feedback fields. A qualified observation must be at least 100 ms after request and strictly before the deadline to verify. Fault or local OFF supersedes the request. Terminal snapshots are retried unchanged while held in RAM; reboot can lose them, so the platform retains its independent timeout/unknown deadline and never infers success.

A durable replay sequence is written before a relay request. Default firmware disables relay actuation and commissioning, independently of any platform UI or command transport. No remote command clears a latched local fault.

## Persistence and cold TLS bootstrap

On-flash namespaces are `cb_journal`, `cb_factory`, `cb_secure`, each statically asserted ≤15 bytes. No deployed unit migration is assumed. Invalid previous overlength names could not have been written by ESP-IDF. Incompatible calibration v2 is rejected without erasure or automatic revision guessing; deliberate re-issuance from a real, fully identified per-unit calibration record is required.

Calibration v3 stores all 24 bytes of the zero-padded full board revision, including A/B/C distinction; CRC is accidental-integrity protection only. No default gains or production calibration files are shipped. This development format accepts 1..1,000,000 calibrated pulses/kWh and requires both coefficient banks to contain data; out-of-scope calibration requires a reviewed format change rather than silently accepting an overflowing scale.

TLS CA, hostname and certificate date verification stay enabled. Before starting MQTT, the endpoint obtains a ≤2-second challenge response signed by an independently commissioned P-256 public key. The canonical signed bytes are `CARBENTRA_TIME_V1\n{nonce}\n{unix_s}\n`; the signature is DER ECDSA-SHA256 encoded as base64. `cb_secure/time_url` is an HTTP endpoint carrying only public challenge/time/signature data, and `time_pub` is the independently provisioned PEM public key. Trust does not come from HTTP. Redirects are refused. No unverified TLS, SNTP or saved stale timestamp bootstraps certificate validity.

the shared platform `edge/time_bootstrap.py` is optional and requires an operator-supplied private-key file plus an independently accurate host clock. It never creates keys. No signer key, device key or certificate is included. The bootstrap runs in its own task so malicious latency cannot block local protection; failed refresh eventually stops MQTT. Provisioning, key rotation/revocation, accurate server time and broker ACL are explicit deployment responsibilities.

## Layer ownership and remaining gates

Firmware owns local protection and observation. Edge owns strict wire ingestion, durable transport, bounded dispatch and retries. Platform owns asset ontology/registry, policies, forecasts, optimization, interval/energy/carbon ledgers, command lifecycle and presentation. Future physical transport requires independent backend and edge opt-ins plus matching operator-attested release records and per-device allowlists; all remain OFF for this digital validation, and firmware actuation remains independently disabled. Device wire data contains no fabricated campus/room/model binding.

A passing target build, host tests or virtual broker loop is digital evidence only. Actual MCU timing/radio/TLS interoperability, relay response, per-unit calibration, power-loss recovery, security hardening and all mains/thermal/insulation/EMC qualification remain independent HOLD gates.

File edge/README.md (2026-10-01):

# Shared Edge runtime

There is no second Plug-only Edge implementation in this repository. The sole runtime is `carbentra-campus-platform/edge`; schemas, semantic validators and canonical examples live in that repository's `packages/iot-contract`.

Set `CARBENTRA_PLATFORM_ROOT` to the actual local platform checkout. No remote repository or deployment URL is guessed. Create its project environment with `uv venv --python 3.12`, install its root `uv.lock` with `uv sync --locked`, then run its `edge/service.py` with the reviewed per-device enrollment/configuration. See the platform Edge README/runbook for MQTT mTLS, HMAC-authenticated Sense GATT, channel control, offline outbox and deployment gates.

For cross-repository verification, set `CARBENTRA_PLATFORM_ROOT` and run `pwsh -NoProfile -File scripts/check_windows.ps1 -BuildTarget` from this hardware checkout. It compiles the actual MSVC/mbedTLS firmware gates and uses the shared platform environment. Tool paths and CAD/GPU checks are documented in [Windows development](../docs/WINDOWS_DEVELOPMENT.md). Missing shared source or dependencies is an error. Named POSIX permission checks execute in the complementary Linux suite; Windows executes all three real firmware integration gates. Evidence records both summaries instead of treating platform-specific exclusions as passes.

Independent hardware CI runs only its own C host regression, PCB evidence and ESP32-C3 compilation. Cross-repository cryptography/wire/MQTT proof belongs to the shared platform integration job/workspace. `PROVENANCE.json` records the retired source snapshot; Git history retains the former code. Historical broker evidence is not asserted against new sources. No physical dispatch gate is enabled by migration.

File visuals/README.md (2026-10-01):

# CARBENTRA visual engineering

This directory is the visual layer of **碳迹未来 · CARBENTRA**. The canonical current assets are under [`rev_b/`](rev_b/); historical revisions remain in Git rather than a duplicate working-tree archive.

All product geometry is derived from the shared mechanical and ECAD sources in their common millimetre coordinate frame. Blender converts those engineering exports to presentation units; it does not substitute an unrelated shell or AI-generated product geometry.

## Current baseline

- **Platform:** CARBENTRA
- **Device:** CARBENTRA Plug
- **Revision:** CARBENTRA-P16-EVT-B
- **Canonical scene:** `rev_b/carbentra_studio.blend`
- **Detailed GLB:** `rev_b/exports/carbentra_assembly.glb`
- **Twin GLB:** `rev_b/exports/carbentra_twin_light.glb`
- **Animation:** `rev_b/animation/carbentra_exploded.mp4`
- **Renders:** `rev_b/renders/`

The active scene includes the CARBENTRA product mark and the Chinese project identity **碳迹未来**. Display-only transparent, exploded and section views are inspection devices, not material or manufacturing claims.

## Reproduce Rev B

From the repository root, after the mechanical and ECAD exports exist, set the Rev B source paths described in [`rev_b/README.md`](rev_b/README.md) and run:

```sh
blender -b --python visuals/scripts/build_studio.py -- all
python visuals/scripts/compose_sheets_zh.py
python visuals/scripts/validate_deliverables.py
```

The Blender pipeline supports `CARBENTRA_USE_GPU=1` for a local CUDA/OptiX render path when available. The annotated-sheet scripts use the repository font asset instead of an OS-specific font path.

## Revision policy

Historical Rev A sources are recoverable from Git (including pre-cleanup commit 763972e), rather than maintained as a second working-tree pipeline. Canonical Rev B generators, scene dependencies and freeze records do not reference the removed archive. Never mix historical dimensions, placement or check results with current release evidence.

## Engineering boundary

Photoreal lighting does not imply a fabricated or tested product. The 220 V AC / 16 A target remains a design target until physical safety, gauge, temperature-rise, insulation, protection, EMC, calibration and reliability work is complete.

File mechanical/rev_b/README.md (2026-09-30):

# CARBENTRA · CARBENTRA-P16-EVT-B

Original integrated smart-plug engineering development assembly. Nominal enclosure 108 × 93 × 65 mm; one 100 × 85 mm main PCB plus a remote temperature pickup. This is a reviewable digital design, not an authorization to fabricate or energize mains hardware.

## Main files
- `CARBENTRA-P16-EVT-B.FCStd`: parameterized mechanical source with editable enclosure, shutter and contact-gap inputs
- `CARBENTRA-P16-EVT-B_mechanical.step`: 71 mechanical parts
- `CARBENTRA-P16-EVT-B_system_assembly.FCStd` / `.step`: mechanical parts, 144 actual exported PCB placement/body/lead objects and 19 transformed head solids
- `parts_manifest.json`, `meshes/`, `parts/`: common-frame meshes, individual STEP parts, materials/grouping and exploded offsets
- `assembly_world_bounds.json`: tessellated per-object and aggregate bounds for transform verification
- `contacts_inserted_nominal.step`, `contacts_inserted_maximum_reference.step`: prescribed 1.8 / 1.95 mm blade-opening states, separate from the unloaded 1.7 mm contact state
- `docs/`: dimensioned front/rear polarity drawing, engineering description and tolerance/release gates

## Validation evidence
`integrated_fit_report.json` records BRep validity, intentional interfaces and unintended interference separately. `contact_engagement_report.json` distinguishes intended spring engagement from rigid insertion obstruction. `shutter_kinematic_report.json` tests the closed, single-pawl and released travel states. `polarity_connectivity_report.json` checks modeled external conductive joints and continuous PE. `insulation_domain_report.json` / `.md`, when generated, are a separate primary/isolated proximity review: collision-free geometry is not electrical-safety approval.

The PCB package solids include nominal/max body envelopes and explicit lead volumes, not complete vendor internal CAD. Detailed PCB copper is supplied separately by the electronics project. Female receptacle gauges, contact force/endurance, dielectric qualification, solder/weld/crimp processes, real thermal behavior, enclosure retention, and wall-socket loading remain release gates.

## Reproduce
Use the installed FreeCAD Python environment with `/usr/lib/freecad-python3/lib` on `sys.path`. Run, in order: `build_base.py`, `validate_integrated_fit.py`, `validate_contact_engagement.py`, `validate_shutter.py`, `audit_connectivity.py`, and `export_release.py`. The build-stage file is intentionally named `CARBENTRA-P16-B-base-provisional.FCStd`; the export script produces the named deliverables above. Keep `socket_b_features.py`, `power_links.py` and `design_parameters.json` alongside native files for proxy regeneration. Rev A files are independent and unchanged.

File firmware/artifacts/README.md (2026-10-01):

# Development-only target artifacts

Current ESP32-C3 binaries are produced by official ESP-IDF 5.4.3 from the source snapshot bound in `../validation.json`. All supplied application images are compiled with actuation disabled. `../target_build.log` and the source/artifact hashes bind the actual build; no earlier binary is substituted.

These files are digital build evidence. Do not flash or energize a unit on the strength of a passing build. Independent hardware release, measured per-unit calibration, owner credentials/ACL and signed-time provisioning remain required. No key or production calibration is included.

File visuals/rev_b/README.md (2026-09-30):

# CARBENTRA · 碳迹未来｜CARBENTRA-P16-EVT-B 可视化

本目录使用共同的机械、主板和远置温度传感头工程源。外壳标称 108 × 93 × 65 mm，单一三孔 16 A 级接口工程目标。数字检查不等于实物装配、量规合格、电气安全认证或可通电许可。

## 文件

- `carbentra_studio.blend`：可编辑完整物理零件场景，保持源网格分件与名称，字体内嵌，使用 Blender 原生压缩保存
- `carbentra_animation.blend`：动画专用刚性分组场景，原零件名称保存在各组 `source_members` 中
- `exports/carbentra_assembly.glb`：完整物理几何，可选择零件
- `exports/carbentra_twin_light.glb`：平台展示轻量模型；保留外观全精度网格与功能零件名，内部使用同一原生 CAD 的 0.04 mm 弦差 / 0.3 rad 角度公差显示网格，铜箔、焊盘和过孔按材质合并。因此不宣称它与完整网格逐顶点相同
- `animation/carbentra_exploded.mp4`：1280 × 1280、24 fps、6 秒的分解／停留／重组动画。动画使用 0.04 mm 显示网格；工程源不受影响
- `renders/`：两张 2400 × 2000 工作室外观图、背面接口、内部结构、透明检查、爆炸图、六视图、剖切图、主板检查
- `exports/deliverables_validation.json`：完成后生成的文件尺寸、哈希、视频参数与源一致性检查

## 几何与显示约定

机械源均为共同坐标系毫米单位。主板 OBJ 的底面位于局部 z=0，仅应用一次 +11.5 mm 的装配平移；HeadB OBJ 已应用正确的 180° X 旋转并置于共同坐标系，不重复平移。导入时统一以 0.001 比例换算为 Blender 米单位。

`exports/import_validation.json` 保存输入哈希、变换矩阵、远置温度头变换来源、原始网格顶点边界与共同坐标验证结果。`exports/common_frame_validation.json` 对照机械总装的主板封装边界。非物理的 RFServiceSlackEnvelope 是空间预留，不作为产品零件出现在产品图和 GLB 中。

分层位移由工程分组派生，属于检查用展示布局，不代表装配或拆解工艺。透明外壳是非物理的检查显示，剖切只作用于场景副本。PCB 图显示真实源铜箔路径及简化封装体；阻焊、塞孔／盖孔、制造工艺和电气安全仍需独立确认。

## 复现

脚本在 `../scripts/`。设置 `CARBENTRA_MECHANICAL_DIR=mechanical/rev_b`、`CARBENTRA_PCB_OBJ=electronics/rev_b/integrated/exports/integrated_assembly.obj`、`CARBENTRA_PCB_Z_MM=11.5`、`CARBENTRA_HEAD_OBJ=electronics/rev_b/integrated/exports/remote_head_assembled.obj`、`CARBENTRA_EXPECTED_ASSEMBLY_BOUNDS=mechanical/rev_b/assembly_world_bounds.json`，并令 `CARBENTRA_OUTPUT_DIR` 指向本目录。实际运行时使用绝对路径。

- Blender 后台运行 `build_studio.py -- technical` 渲染技术图；`hero` 渲染两张外观图；`views` 渲染六视图
- 运行 `prepare_animation_lod.py`，再以 `CARBENTRA_ANIMATION_LOD_DIR` 指向输出目录，执行 `build_studio.py -- animation`
- 在完整 studio 场景上运行 `export_twin_light.py`，`CARBENTRA_TWIN_LOD_DIR` 指向同一动画显示网格目录
- 运行 `compose_sheets_zh.py` 生成中文注释图，最后运行 `validate_deliverables.py`

`_preview/`、`_staged_*`、`_animation_benchmark/` 是过程材料，不应作为验证通过的最终工程源交付。实际完成状态以 `RELEASE_STATUS.json` 和最终验证报告为准。

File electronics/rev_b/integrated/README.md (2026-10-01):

# CARBENTRA · CARBENTRA-P16-EVT-B electronics

**Routed engineering development candidate. Fabrication and energization remain on hold.**

This revision integrates edge control, isolated metering, post-switch AC-presence feedback and an independent thermal permission latch on a 100 × 85 mm, four-layer board. It retains a separate 12 × 12 mm thermal pickup head and in-enclosure main protection components. The proposal is a single 220 VAC ±10% socket platform with commissioned load profiles, not a universal plug-hole adapter or an unconditional 16 A motor-switching rating.

## Open these files first

- `integrated.kicad_pro`, `integrated.kicad_sch`, `integrated.kicad_pcb`: editable native project
- `exports/schematic.pdf`: six readable functional/assembly sheets
- `electrical_bom.csv` and `electrical_manifest.json`: numbered pins, real candidates and primary-source links
- `ELECTRICAL_SOURCE.md`: circuit and interface definition
- `POWER_CURRENT_REVIEW.md`: current paths, copper-loss calculations and fault limits
- `RAIL_BUDGET.md`: the IRM-10-5 supply reservation and temperature derating
- `validation/final_summary.json`: current board-hashed verification results

The final main board has **101 electrical items plus four mounting footprints**. Of those electrical items, 99 have physical component bodies and two are zero-height test pads. There are 321 unique numbered main-board pad keys. The full six-sheet assembly graph has 348 numbered terminals, including the remote head, harness models and off-board protection.

## What is implemented

- ESP32-C3-WROOM-02U, external antenna connection, programming/boot controls, local button, status LED and polled TMP102 board temperature
- IRM-10-5 isolated 5 V supply and AP63203 3.3 V buck; conservative concurrent reservation 3.885 W, with manufacturer derating kept explicit
- Four-terminal 1 mΩ shunt, graded voltage divider, ATM90E26, 8.192 MHz oscillator, ISO6741 SPI isolation and an R05CT isolated supply for the mains-referenced metering domain
- ACPL-K376 post-switch AC-presence detector; this reports voltage presence, not a certified absence-of-voltage indication or mechanical contact position
- Remote TMP302 threshold sensor, power supervisor, set-dominant hardware trip behavior, local physical rearm edge and independent coil-supply gating
- Defined main fuse → thermal link → protected line → shunt → relay → output path, plus continuous unswitched PE outside the PCB
- Fully connected four-layer copper, an isolated logic return plane, mechanical hole keepouts and modeled through-hole lead reserves

`HOT_GND` is **line potential**, never PE or isolated logic ground. The main fuse is SHF 8020.5080 with two CQP 8040.0003 clips on a retained insulating carrier. F501 is a separate 1 A auxiliary-supply fuse. The thermal link responds to temperature; it is not an overcurrent fuse. There is no active current-limiting circuit. The software reference does not establish an independent, commissioned current-duration trip.

## Verification and its boundary

The canonical results are `final_drc.rpt`, `final_erc.rpt`, `final_pin_audit.json`, `final_isolation.json` and `final_source_graph.json` under `validation/`. Historical intermediate results are retained in Git; only current canonical reports are kept in the working tree.

- Native DRC: zero violations, zero unconnected items, zero footprint errors
- ERC: zero errors and zero warnings
- Independent schematic-to-PCB pin comparison: all 321 main-board keys match
- Independent projected isolation audit: includes all copper layers, unused isolator pins and the complete conservative ground-plane outline; minimum component land gap 8.10 mm; routed copper/plane targets at least 8.4 mm
- Negative controls: a synthetic 6 mm gap is rejected by the supported KiCad rule, and a shifted hot pad is rejected by the independent checker
- Rebuild: placement/net geometry is checked before the saved copper recipe is replayed; no undocumented autorouter state is required

**These are digital checks, not manufactured insulation or current ratings.** The 8.10 mm component-land minimum has only 0.10 mm nominal reserve above the preliminary 8 mm rule. Finished land geometry, solder spread, contamination, creepage, material group, altitude, dielectric construction and measurement tolerances still require a qualified insulation design review. The 2.5 mm open-contact and 3 mm neutral functional rules are preliminary engineering constraints, not a standards-compliance claim.

A negative-control investigation found that earlier JavaScript-style `NetName.startsWith(...)` conditions were not enforced by KiCad. This revision uses supported wildcard comparisons and records both the failing old control and corrected control. The frozen EVT-A baseline was not rewritten; see `../BASELINE_RULE_LIMITATION.md`.

## Physical exports

- `exports/placement_assembly.step`: 144 valid solids for component/body/lead fit checking
- `exports/integrated_assembly.step`, `.FCStd`, `.obj`: 3133 valid solids including actual native pads, traces and vias
- `exports/component_envelopes.json`: component and lead bounds
- `exports/remote_head_assembled.step`, `.obj`, `.json`: 19 valid head solids in final assembly coordinates, with an explicit proper rigid transform and source hash

Main-board exports use millimetres, centered XY, board bottom at local z=0; the mechanical assembly translates MainB by +11.5 mm in Z. The HeadB export is already in assembly coordinates and must not receive that translation. Its pickup copper face is at z=43.5 mm. Copper is raised/colored for inspection; solder mask/tenting and detailed manufacturer body geometry are not qualified by the visualization. Native KiCad copper and plane files remain authoritative.

## Required release gates

1. Confirm the applicable plug/socket standard, market, altitude, insulation class and actual 198–242 VAC operating requirement. The 264 VAC calculation point is measurement headroom only.
2. Obtain actual prospective fault current, upstream breaker curve and fuse total-clearing data. SHF's stated 760 A²s is typical **melting** I²t at 10× rated current, not an upper bound on total let-through. Qualify every trace, via, shunt, terminal, collector, wire and joint accordingly.
3. Test enclosed 16 A temperature rise and short-circuit containment. The copper-loss model and 70 µm outer-copper proposal are not a finished-board current rating. Verify plating, current sharing, solder joints, fuse-clip retention and enclosure heat.
4. Obtain the intended load's steady current, locked-rotor/inrush waveform, repetition rate and switching duty. The relay's resistive rating does not release a 16 A compressor, transformer or capacitive load.
5. Calibrate voltage/current/power/energy with traceable references and signed profile data. Verify shunt polarity, startup checksums, timing, waveform range and overrange behavior. Firmware contract: `../FIRMWARE_CONTRACT.md`.
6. Test thermal pickup lag, threshold spread, pressure/aging of the insulating pad, sensor/pigtail failures, slow power ramps, local rearm and welded contacts. Ideal latch tests cannot prove this physical behavior.
7. Complete EMC/surge/EFT, RF/antenna integration, dielectric/impulse, creepage/clearance, abnormal-operation, mechanical gauge/retention and production reliability testing.
8. Obtain board-house approval of the four-layer stack, 0.20 mm finished signal-via drills, via-in-pad/tenting/fill process and all authored land patterns before any fabrication release.

Power restoration starts de-energized and requires the defined thermal rearm/commissioning sequence. Runtime unknown-load, stale-meter and offline behavior must follow the commissioned policy; they are not universal instructions for abrupt power removal. See the repository's system/network and sensor documentation.

## Rebuild

Use `bash scripts/rebuild.sh --no-geometry` for a source/copper/verification rebuild, or omit the option to regenerate geometry. KiCad 9, its standard libraries, system Python with pcbnew/NumPy, FreeCAD, Inkscape, ReportLab and pypdf are required. The script validates geometry against `routing_recipe.json` before applying copper and then reruns the independent checks. Local vendor-PDF research caches are not required deliverables; official URLs remain in the BOM and authored notes.

## Rear termination integration correction

The corrected front/rear polarity exposed an assembly-level clearance problem that native PCB-domain DRC could not detect. The rear L tail was lowered by the mechanical design, the nearby +5 V and +3.3 V branches were rerouted, and the internal GND plane was recessed. All component placements remain fixed. `validation/rear_termination.json` independently checks the resulting rear metal against native isolated copper, including the conservative entire plane outline. The nominal minimum is 8.5166 mm, versus an 8.4 mm design check. This is not a tolerance-qualified clearance or creepage result. The complete mechanical insulation-domain report remains a separate release gate.

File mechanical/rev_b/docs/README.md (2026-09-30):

# CARBENTRA CARBENTRA-P16 · Rev B 机械工程开发包

**技术版本：CARBENTRA-P16-EVT-B · 文件日期：2026-09-30**
**状态：工程开发 / 制造与通电放行未通过。本文不声明最终几何审计、样机试验或产品认证通过。**

Rev B 采用原创 108 × 93 × 65 mm 名义外壳和一块 100 × 85 mm 集成主板，不是把四块实验模块简单叠放，也不是供应商产品的内部复原。目标为单个三孔、16 A 等级、220 VAC 智能插座。16 A 是设计目标，不能解释为本封闭外壳已经具备持续额定载流能力；无 10 A 或万能插孔兼容承诺。

## 先看这些文件

| 文件 | 用途与边界 |
|---|---|
| [正反面极性与接口控制图 PDF](CARBENTRA-P16-EVT-B_face_view_polarity.pdf) / [SVG](CARBENTRA-P16-EVT-B_face_view_polarity.svg) | 原创外壳正视、后视、接口尺寸与投影；工程控制图，不是量规或制造图 |
| [绝缘域几何审计](../insulation_domain_report.md) / [完整数据](../insulation_domain_report.json) | 当前同版本裸端、保险丝/热切断器、焊脚、PCB铜/填充区及操纵件/螺钉的3D距离；不等于合格绝缘 |
| [公差与放行门槛](TOLERANCE_AND_RELEASE_GATES.md) | 已知尺寸区间、名义间隙、未闭合的公差链和放行证据 |
| [设计参数](../design_parameters.json) | 外壳、PCB、接触载体、操纵件与接口的输入值 |
| [机械参数特征](../socket_b_features.py) / [导体路线](../power_links.py) | 当前原生几何的计算来源；图纸与它们不一致时必须调查，而非默认为某一方通过 |
| [早期封装研究](../PACKAGING_STUDY.md) | 历史方案比较；其中早期高度、柔性线方案和重量假设不作为当前放行依据 |
| [集成电子源说明](../../../electronics/rev_b/integrated/ELECTRICAL_SOURCE.md) | F601/F501/TF601 区分、主通路、候选器件及电气设计边界 |

检查模型应使用本次重新生成的原生 FreeCAD 装配、相应 STEP、逐对实体审计、插脚扫掠和保护门运动报告。原有报告若未绑定本次几何/PCB版本，不得复用其通过结论。文件名称中带 `provisional` 不会因有了本文而转为制造放行。

## 1. 统一坐标、正反面极性

- 单位 mm；原点为名义后壳背面中心，z = 0；前表面 z = 65
- +Z 指向正面，+Y 向上，+X 在正面视图中向右
- **正面插座直接看孔，视线沿 −Z：L 右、N 左、PE 上**
- **背面插头直接看插脚，视线沿 +Z：L 左、N 右、PE 上**
- 后视图只改变观察方向，不能再次改变实际接线或交换世界坐标中的 L/N

| 导体 | 世界 X | 世界 Y | 长轴相对 +Y 的旋转（绕 +Z） |
|---|---:|---:|---:|
| PE | 0 | 11.1000000 | 0° |
| L | +8.2272413 | −4.7500000 | −30° |
| N | −8.2272413 | −4.7500000 | +30° |

L/N 坐标由 F = 9.5 的三角关系得到：X = ±F cos 30°，Y = −F sin 30°。中心横距 16.4544827；PE 至 L/N 中心水平线的高度差 15.85。Volex 图中的上侧 2.2 mm 虚线是供应商插头本体参考，不是本项目原点，不能再次叠加到上述坐标。

本项目只利用 Volex 2025 GB16C 图作**标准化配合接口的尺寸交叉检查**；外壳、布局、载体、导体和保护门为原创。该厂商产品的额定值、CCC 标识与符合性均不转移到 CARBENTRA。

## 2. 当前名义封装

| 项目 | 当前设计输入 |
|---|---|
| 外壳 | 108 × 93 × 65；平面外角 R14；名义壁厚 2.4；后底 3 |
| 盖合界面 | z = 56；前壁内面 z = 62.6；外面 z = 65 |
| 背向插脚 | L/N 18；PE 21；L/N 根部绝缘套名义长 9 |
| 含插脚的轴向包络 | 名义 86（z = −21 至 +65）；L/N 投影到 −18 |
| 主板 | 100 × 85 × 1.6；R10；板底 z = 11.5，板顶 z = 13.1 |
| 上表面器件高度预算 | 板顶以上 23，对应名义最高 z = 36.1；不是每个器件的真实实体 |
| PCB 安装孔 | 四个 Ø3.2，(±44, ±36)；孔周 Ø7 禁布/装配预算 |
| PCB 左缺口 | X −50…−38，Y −22…−8，供 L/N 立向导体通过 |
| PCB 右缺口 | X +44…+50，Y +12…+22，供独立 PE 通道通过 |
| 插接载体 | 主体 60 × 50；z = 41…57；L/N 底座 z = 44；上压紧部至 62.6 |
| 操纵件中心 | 本地按钮 (+24, −34)，复位 (+38, −25)，状态灯 (+34, +34) |
| 前面板开孔 | 按钮 Ø8.4、复位 Ø4.4、灯孔 Ø2.8；按钮/光导自身尺寸与孔不同 |

名义元件顶面 z36.1 至载体底 z41 的高度差为 4.9。它是局部包装预算，不是可随意布线的整层空间，也不是电气安全距离。焊脚、F501 板底件、导体、真实连接器和支承都必须参加实际实体检查。

`RearFinish` 为薄装饰环时可能比名义外轮廓多出总宽/高 0.08 mm；最终最大外形必须从本次实体包围盒读取并在制造图上冻结，不能把 108 × 93 的名义值冒充测量值。

## 3. 主通路与保护器件不能混同

**主负载 L：后 L 插脚 → F_MAIN（电气 F601）→ TF1（电气 TF601）→ J201.1 → 板上分流器/继电器 → J102.1 → 前 L 插套。**
N 经 J201.2、板上 N 通路和 J102.2 连续；PE 从后 PE 插脚沿独立导体直接至前 PE 插套，不经 PCB、继电器或保险丝。

| 部件 | 当前候选 / 位置意图 | 不代表什么 |
|---|---|---|
| F_MAIN / F601 | SCHURTER SHF **8020.5080**，16 A 快断，6.3 × 32 系列；名义外形 31.8 × Ø6.35 | 不是主动限流器；熔化 I²t 不是总开断 I²t 或下游可承受能量上界 |
| 主保险丝夹 | 两个 SCHURTER CQP **8040.0003**，独立 45 × 16 × 2 绝缘载板、铜集流片及机械压持 | 夹子的单件额定值不是自制座的封闭热容量或绝缘认证 |
| TF1 / TF601 | MICROTEMP G5 独立一次性热切断器；邻近接触热点，套管与压持件 | 候选 110°C 动作温度、订货后缀、热耦合和焊接工艺均未放行 |
| F501 | Littelfuse **0215001.MXEP**，板底独立 1 A 延时辅助电源支路保险丝 | 不承担 16 A 主负载保护；F501 前的引线仍依赖主保险丝保护 |

当前接触件已替换为原创双叶簧候选：名义叶厚0.4、未插入缝隙1.7；独立原生参数ContactGap用于1.8名义插入态和1.95最大参考脚厚态，名义每叶横向挠度分别0.05与0.125。它修正了早期2.2宽松空槽的几何问题，但材料牌号/硬态、镀层、成形半径、力学应力、接触力、温升及疲劳均未验证，不能当作合格簧片。

保险丝本体、夹子和引脚以核对过的名义/最大外形建模，仍不是供应商完整弹片、镀层、内部结构或公差 CAD。CQP 四孔排列、夹紧接触、铜集流片端接和可装配顺序须以实物与制造图确认。

## 4. 六条原创成形铜导体与独立 PE

当前 L/N 主回路使用六条自定义退火 **Cu-ETP 实心圆铜 Ø2.0 mm** 导体（截面积约 3.14 mm²），不是早期 2.5 mm² 柔性线方案。中心线使用真实圆弧，最小设计成形半径 R6；R6 是几何输入，未证明反复弯折寿命或工艺可行性。

| 路线 ID | 连接意图 |
|---|---|
| L_RAW | 后 L 插脚 → 主保险丝输入铜集流片 |
| N_RAW | 后 N 插脚 → J201.2 |
| L_FUSE_THERMAL | 主保险丝输出铜集流片 → TF1 一端 |
| L_PROTECTED | TF1 另一端 → J201.1 |
| L_OUTPUT | J102.1 → 前 L 插套引出片 |
| N_OUTPUT | J102.2 → 前 N 插套 |

导体保持于专用刚性绝缘载体内：名义外径 4.4、内径 2.4、径向壁厚 1.0；路由周围保留额外 0.25 径向安装预算。端子入口名义 z20.6，模型保留 ±1.0 的入口高度不确定性和约 8 mm 直段接入。**端子是否允许这种成形实心端头、端头处理、夹紧力、防松与拉拔试验均未确认。** 包络重叠仅表示预期接入，不能证明真实夹口有接触。

后L插脚内部宽片至z5；后N宽片至z3.2，中央圆柱端头至z6.5；L输入铜杆接头中心z5.7。该降低后端端接的方案与PCB局部改线共同接受几何审查，外部插脚伸出21/18的接口尺寸不变。

PE 是另一条独立铜通路及绝缘通道。CAD 并集连通不证明接地电阻、接合强度或故障电流承受能力。所有铜材料、镀层、连接工艺及故障保护配合须由专业人员审查。

## 5. 保护门、热耦合与装配固定

- 保护门有共同滑块、两个独立压下的锁爪、锁爪弹簧和回位弹簧；名义闭合行程 0，打开行程 12.5。现有机构用于数字运动研究，不宣称已通过单极插入、防误触或寿命试验
- 应同时验证闭合遮挡、双脚开启、单脚阻挡、释放后复位、弹簧压并、脱扣和塑料蠕变。只在终点无干涉不能证明全行程无卡滞
- 传感头采用接触热点旁的电绝缘导热路径，候选 0.5 mm KERATHERM 86/60 片。材料击穿试样数据不能当作整机加强绝缘；边缘爬电、压缩、防切穿、防移位及真实温度滞后均开放
- L/N 极性修正后，当前传感头中心为(+10.8272413, −4.75)，导热片中心为(+8.2272413, −4.75)；传感头绕X翻转180°，热耦合背面名义z43.5。传感头、导热片、TF1 与 L 插套仍必须以本次组合实体检查
- PCB 固定、载体承台与前盖压持、主保险丝夹载板/压持件、热切断器压持、导体载体、按钮导向均是可检查对象；当前螺钉以名义螺纹大径包络表示，导孔接合长度约3–4 mm；实际螺钉系列、导孔尺寸公差、扭矩、装配工具路径、维修安全及长期保持力仍未冻结

## 射频线缆与连接器装配边界

所选天线带100 mm同轴，当前名义引线路由约56 mm；其余约44 mm已分配到有保持导向的服务环路预留区。非实体环形包络RFServiceSlackEnvelope中心(23,35.8)，内/外半径6.1/7.95，z46.5–50.5；前盖在x16/30、y35.8有两个一体导向卡扣。该预留按约7 mm环路半径及R≥6 mm假设布置，代表空间分配，不是精确电缆中心线路由。制造商允许弯曲半径、实际装配余量、保持力及连接器应力释放仍需资格验证。该参考对象默认隐藏、非物理零件，不计入71件物理部件或质量。实际配对RF连接器与传感头排针外壳目前是标识过的包络，不能作为精确配合或保持力证明。

## 6. 包络与真实性等级

| 证据等级 | 本包能支持的判断 | 不能外推到 |
|---|---|---|
| 参数与原创形体 | 当前设计输入、空间安排、名义运动关系 | 厂商精确 CAD、制造公差或合格标准接口 |
| 同坐标名义/最大器件包络 | 明显穿透和空间冲突；必须包含板底器件与焊脚 | 实际卡扣、引脚弯曲、夹口、供应商装配公差 |
| 本次 BRep / 扫掠检查 | 所检查对象和状态中的几何干涉或连通 | 电气间隙、爬电、接触力、耐压、热安全或认证 |
| 未来专业测量/试验 | 仅对应完成的试验条件与样品 | 未测量的长期可靠性或其他使用条件 |

不提供实测质量、重心、墙插静力矩、温升或插拔力。早期封装研究中的质量和力矩区间是敏感性假设，不能成为产品规格。墙面保持需包含外接插头、电缆垂重及牵拉工况。

## 7. 放行流程

完整门槛见 [TOLERANCE_AND_RELEASE_GATES.md](TOLERANCE_AND_RELEASE_GATES.md)。至少先完成：

1. 冻结同版本 PCB / 机械 / 物料 / 坐标；重新生成所有导体清单、装配和审计
2. 用正式 GB 1002-2024 图纸与适用量规确认正反面接口；完成完整公差链和配对件极限状态
3. 完成主回路、PE、保险丝/TF1、导体端接、接触力与绝缘结构的专业评审
4. 先做不通市电的装配/运动样件，测保持、全行程、端接、机械耐久与材料行为
5. 在合格设施按批准计划进行接地、绝缘、温升、故障、保护配合、EMC及认证相关试验

**没有任何几何通过记录可单独解除通电与制造放行限制。**

## 来源

- [Volex Power Cords Catalogue, Aug 2025，PDF第36页，GB16C](https://www.volex.com/media/0dodxec5/volex-power-cords-catalogue-august-2025.pdf)：只用于标准配合接口交叉检查；图中商品外壳未复制
- [国家标准全文公开系统：GB 1002-2024](https://openstd.samr.gov.cn/bzgk/std/newGbInfo?hcno=F8C9E208891B7BB5AF1B3E64933693C2)：官方记录显示现行、2025-08-01实施；本包未完成授权标准尺寸/量规验证
- [SCHURTER SHF 6.3×32](https://www.schurter.com/en/datasheet/typ_SHF_6.3x32.pdf) 与 [CQP](https://www.schurter.com/en/datasheet/typ_CQP.pdf)：候选主保护组件
- [Littelfuse 215](https://www.littelfuse.com/assetdocs/littelfuse_fuse_215_datasheet.pdf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)：F501辅助支路保险丝
- [Kerafol 2026 KERATHERM 目录，纸面48页 / PDF第25页](https://www.kerafol.com/wp-content/uploads/2026/05/Kerafol_Katalog_Keratherm_Web_06-26.pdf)：候选导热绝缘材料，非整机绝缘批准

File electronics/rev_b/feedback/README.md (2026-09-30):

# Rev B isolated post-switch output detector

**Development candidate. Do not fabricate, connect to mains, or treat any signal as a safety indication.** Baseline EVT-A files were not edited. This is a separate, routed Rev B source module, not a certified socket or a release to energize.

## Result and interface

A 35 × 25 × 1.6 mm, two-layer module senses differential voltage at the **actual output socket L and N contacts**, after every switched pole. It uses a full-wave AC-input threshold optocoupler, four protective-impedance resistors and isolated 3.3 V logic. It needs one MCU GPIO capable of observing pulses, plus isolated power and ground. No load current is required.

- J1: L_POST, socket-side line sense only
- J2: N_POST, socket-side neutral sense only
- J3.1: +3V3_ISO; J3.2: GND_ISO; J3.3: OUTPUT_PRESENT_N
- Logic: recurring active-low pulses at twice mains frequency; LOW by itself is not a complete measurement
- Reserve **9 mm above PCB, 3 mm below PCB**, plus mating connector and wire bend/strain-relief space. These are keepout reservations, not a validated complete assembly envelope
- No protective earth conductor or load-current path is routed on this module

`output_feedback.kicad_sch`, `.kicad_pcb`, `.kicad_pro`, `.kicad_dru`, `Feedback.kicad_sym`, `Feedback.pretty/`, `pin_net_manifest.json` and `bom.csv` are the design sources. `exports/` contains schematic and board-review SVG/PNG plus the exported KiCad netlist. `scripts/build_feedback.py` rebuilds the source; `scripts/verify_feedback.py` independently checks connectivity, domain spacing and calculations. No Gerbers or fabrication package is provided.

## Circuit and pin correctness

The implemented signal path is:

L_POST → R1 33 kΩ → R2 33 kΩ → U1 pin 1 (AC1)

N_POST → R4 33 kΩ → R3 33 kΩ → U1 pin 4 (AC2)

U1 is **Broadcom ACPL-K376-560E**. Its internal bridge and input threshold controller feed the optical isolation stage. Pin 8 is isolated VCC, pin 5 isolated GND, pin 6 open-collector output. Pins 2 (DC+), 3 (DC−), and 7 (NC) are intentionally unconnected. R5, 1.8 kΩ, pulls pin 6 to isolated 3.3 V; C1, 100 nF, bypasses its isolated supply. There is no rectifier storage capacitor or mains-to-MCU resistive divider.

The source pin table was visually checked against the manufacturer functional diagram, not inferred from a generic optocoupler symbol. The four resistors are split across both input legs; **neither leg is considered touch-safe or guaranteed neutral**. Their intermediate nodes remain in the primary domain. [Broadcom datasheet, pp. 1–2](https://docs.broadcom.com/doc/AV02-2153EN)

## Why this topology

Three options were compared:

1. **H11AA1 AC phototransistor:** simple and naturally reverse-protected. However, its minimum CTR is 20% at ±10 mA, VCE = 10 V, 25°C. That is not a guarantee at ~1–2 mA, hot, aged, or saturated. At 198 VAC, obtaining 10 mA at the crest requires about 27.85 kΩ or less; at 264 VAC the resistor loss is then approximately 2.50 W before tolerance. Unnecessarily hot for a compact socket. [Vishay H11AA1 datasheet](https://www.vishay.com/docs/83608/h11aa1.pdf)
2. **Discrete 1000 V bridge + VO615A-4 phototransistor:** the 56% minimum CTR at 1 mA is useful, but it is specified at VCE = 5 V and 25°C. Multiplying that CTR into a saturated 3.3 V GPIO interface would overstate the guarantee. A transistor solution requires separate low-VCE/temperature/aging qualification or an appropriately biased comparator design. [Vishay VO615A datasheet](https://www.vishay.com/docs/81753/vo615a.pdf)
3. **Selected ACPL-K376 integrated bridge + threshold optocoupler:** threshold detection occurs before the optical transfer path, so the detector is specified by input threshold limits rather than a guessed CTR minimum. The manufacturer covers −40…105°C and includes 3.3 V operation. The component isolation ratings do not certify this PCB or assembly. [Broadcom datasheet, electrical tables](https://docs.broadcom.com/doc/AV02-2153EN)

This choice still contains a bridge and optocoupler; the bridge is integrated. There is no external diode footprint that can be assembled with the wrong AC/DC pin order.

## Component candidates and footprint basis

| Ref | Candidate | Mechanical/footprint basis |
|---|---|---|
| U1 | ACPL-K376-560E | Manufacturer SSO-8, custom `Feedback:SSO8_ACPL_K376`; body 6.807 ±0.127 × 5.850 ±0.50 mm, max height 3.307 mm; 1.27 mm pin pitch; lead span 11.50 ±0.25 mm |
| R1–R4 | Vishay PR01000103302FA100 | PR01, 33 kΩ, ±1%, 1 W at 70°C, 350 V working-voltage ceiling; custom horizontal 10.16 mm pitch, 0.9 mm drills; max body 6.5 × 2.5 mm; 0.58 ±0.05 mm leads; assembly standoff/lead forming still to qualify |
| R5 | Yageo RC0603FR-071K8L | 1.8 kΩ ±1%, 1608 metric; KiCad 0603 footprint; ordinary isolated-side pullup |
| C1 | Murata GRM188R71C104KA01D | 100 nF ±10%, X7R 16 V, 1608 metric; KiCad 0603 footprint |
| J3 | Samtec TSW-103-07-G-S | 2.54 mm pitch, three 0.635 mm square pins; vertical 1×3 header footprint; 5.84 mm mating post + 2.54 mm body = 8.38 mm nominal above board |
| J1, J2 | Internal insulated wire solder lands | Custom 1.2 mm drill / 2.4 mm copper diameter; **final wire gauge, insulation, anchoring and strain relief remain HOLD**, not a rated detachable mains connector |

U1's custom pads are 1.905 × 0.65 mm, with opposed pad centers 10.745 mm apart. The resulting pad-edge distance is 8.84 mm; the 0.65 mm width follows a practical KiCad SSO-8 land width, wider than the maximum 0.511 mm component lead. The 12.65 mm outer land span follows the manufacturer drawing. A 1 mm wide, 21 mm long routed slot under the package provides extra surface-contamination margin. **This is not permission to reduce air clearance.**

PR01 has a non-flammable coating and documented active/passive flammability tests; it is **not an agency-qualified safety fuse in this use**, and an unspecified benign open-circuit failure is not assumed. Its power/voltage/pulse/load-temperature limits all apply. [Vishay PR01 family datasheet](https://www.vishay.com/docs/28729/pr010203.pdf), [Samtec exact header](https://www.samtec.com/products/tsw-103-07-g-s), [Murata exact capacitor](https://www.murata.com/en-us/products/productdetail?partno=GRM188R71C104KA01D)

## Worst-case electrical calculations

The target is sinusoidal **198–264 VAC, 50/60 Hz**. Distorted/phase-cut waveforms require separate tests. This detector is not an RMS voltmeter. All numbers below are calculations, not bench measurements.

RΣ = 4 × 33 kΩ = 132 kΩ. Initial ±1% gives RΣ,min = 130.68 kΩ and RΣ,max = 133.32 kΩ. High-line peak is 264√2 = 373.35 V; low-line peak is 198√2 = 280.01 V.

Use the component's all-temperature AC-input limits:

- ION,max = 1.56 mA, VON,max = 5.5 V
- IOFF,max = 0.80 mA, VOFF,max = 4.42 V
- ION,min = 0.87 mA, VON,min = 4.23 V
- IOFF,min = 0.43 mA, VOFF,min = 2.87 V

These are instantaneous thresholds. Their extreme combinations are deliberately conservative; correlation is not relied on. [Broadcom datasheet, table 6](https://docs.broadcom.com/doc/AV02-2153EN)

Vsource,on,max = ION,max RΣ,max + VON,max = **213.48 V instantaneous**, or 150.95 VAC if interpreted only as a sine-wave crest threshold. That remains below the 198 VAC crest by 66.54 V. Vsource,off,max = **111.08 V instantaneous**. This broad threshold spread is why amplitude is not reconstructed from a binary reading.

Ignoring the input device's voltage drop gives conservative resistor power/current upper bounds:

- PΣ ≤ VRMS²/RΣ,min = **0.5333 W** at 264 VAC
- Ipeak ≤ √2 VRMS/RΣ,min = **2.857 mA**
- Individual resistor mismatch: Pi ≤ VRMS² Ri/(ΣRj)²; Vi,RMS ≤ VRMS Ri/ΣRj
- Exhaustive ±1% corners give **0.1347 W and 67.00 VRMS** worst for one resistor, not simply PΣ/4
- With one resistor shorted, three remain: **0.7111 W total**, **0.2386 W / 89.18 VRMS** worst remaining part, Ipeak ≤3.809 mA

An additional **±10% resistance analysis envelope** is included in `calculations.json`. This is an engineering allowance, not a manufacturer lifetime guarantee: it accommodates initial 1%, roughly 3% temperature contribution including self-heating, and the 5% endurance-test drift figure with multiplicative headroom. Real mission-life drift, enclosed thermal gradients and pulse damage must be qualified. The margin still supports the target sine-wave range; consult the machine-generated values for exact results. Expected high-line resistor heat is approximately **0.59 W maximum** within that allowance. Do not substitute four unspecified miniature chip resistors.

For one resistor open, a single gap may see the full applied voltage; do not claim the remaining series resistors divide that voltage. An optocoupler input short leaves the series impedance current-limiting; multiple resistor shorts or a carbonized PCB fault are not covered by this simple model. A normal ampere-rated socket fuse may not clear a low-current overheating fault: fuse/impedance coordination and abnormal-condition tests remain mandatory.

### Logic and pulse timing

The 1.8 kΩ pullup sinks at most approximately 1.95 mA with a 3.3 V ±5% rail and −1% resistor. A conservative 100 µA off-leakage allowance leaves at least **2.953 V** at VDD = 3.135 V and Rpullup = 1818 Ω, before host input leakage. Check the actual MCU VIH/VIL specifications, supply tracking and injection-current limits. The datasheet has 3.3 V switching characterization; its 0.4 V static VOL test is stated at VCC = 4.5 V / 4.2 mA, so **the exact 3.3 V low-state margin is still an application verification item**, not silently extrapolated into a new full-temperature guarantee.

For a sinusoid with angular frequency ω, the low pulse width is:

TLOW = [π − asin(VON/Vpeak) − asin(VOFF/Vpeak)] / ω

The high interval around a zero crossing is:

THIGH = [asin(VON/Vpeak) + asin(VOFF/Vpeak)] / ω

At initial tolerance, the shortest calculated low interval across 198–264 VAC is **4.952 ms at 60 Hz**, and the shortest high interval is **1.274 ms**. The wider resistance allowance remains comfortably millisecond-scale. Propagation delays, actual GPIO thresholds and parasitic capacitance shorten or lengthen observed intervals. Use interrupt timestamps or ≥2 ksample/s polling; do not apply a multi-millisecond hardware RC that erases zero-crossing gaps.

Recommended firmware contract:

1. Begin in UNKNOWN after power-up, brownout, reconnect or missing data
2. Accept AC_PRESENT after at least three well-formed pulse periods, expected roughly 8.33/10 ms; provisionally allow 7.5–11.5 ms for qualification, reject isolated sub-0.4 ms spikes and require both levels
3. No valid pulses for 40 ms means **NO_AC_PULSES_DETECTED**, never SAFE, DEAD, ISOLATED or RELAY_OPEN
4. A sustained LOW for 25 ms means **PRESENT_OR_STUCK_LOW / FAULT**, including possible DC/backfeed or a shorted detector output
5. For an OFF command, allow relay release/bounce/settling before comparison (provisional 100 ms); persistent qualified pulses latch an output-present-after-OFF fault, inhibit new ON commands, and request service
6. For an ON command, missing pulses means supply/contact/wiring/sensor fault or unavailable supply; do not repeatedly chatter the relay trying to diagnose it
7. Confirm these provisional windows with the chosen relay and worst-case waveform; software examples alone are not a safety mechanism

## What the signal cannot establish

- A welded contact and a deliberately closed contact can produce the same reading
- An open sense resistor, disconnected wire, dead 3.3 V supply, optocoupler failure or stuck-HIGH GPIO can all hide a live output
- With open neutral, both socket conductors may be live relative to earth while their differential voltage is too small to detect
- Phase-cut voltage, pulses shorter than the detection window, voltage below the threshold, and DC are outside a simple AC-present interpretation
- Capacitive coupling or an RC snubber across an open relay can energize the output enough to produce a real presence indication; that is not necessarily a welded contact
- External backfeed may energize the socket with the relay open
- This is electrically separate feedback from the metering data/relay command, but not a fault-tolerant safety channel, mechanical-position sensor or absence-of-voltage tester

The correct UI phrasing is **“Output voltage detected”**, **“No AC pulses detected”**, or **“Output sensing fault/unknown”**. Never display “Safe to touch” from this module.

## Discharge and stored energy

There is no deliberate primary-side storage capacitor on the detector. The input path loads the output and can discharge some attached capacitance while its internal circuit conducts, but it is nonlinear at low voltage. **No guaranteed discharge time or safe residual voltage is claimed.** A device plugged into the socket, snubber/X capacitor, or backfed circuit may retain energy independently. If discharge is an applicable requirement, design and validate a separate rated bleeder network for the actual capacitance/energy, including its open-circuit fault; never infer compliance from this sensor.

## Independent thermal protection recommendation

These parts belong to the control/load assembly; they are **not fitted on this 35 × 25 mm detector**. The TMP302/latch/coil-feed circuit is implemented separately in `../thermal/`; the series thermal cutoff remains an external integration hold.

1. **Hardware sensor:** TI TMP302BDRLR, SOT-563, 1.6 × 1.6 × 0.6 mm envelope. Pin 1 TRIPSET0 and pin 6 TRIPSET1 to GND select a provisional 70°C trip; pin 4 HYSTSET to 3.3 V gives 10°C hysteresis. Pin 2 GND, pin 5 VS, pin 3 active-low OUT; use 10 kΩ pullup and local 100 nF bypass. Place it at the validated thermal pickup, away from the detector resistor heat. Its ±2°C device accuracy does not bound temperature error between the socket contact and sensor. [TI pin table and application](https://www.ti.com/lit/gpn/TMP302)
2. **Hardware-dominant shutdown:** route the thermal signal to a set-dominant fault latch / coil-enable path as well as the MCU. Power loss or invalid thermal supply must default to relay-disabled. Hold the relay disabled through the sensor startup interval, at least the specified ~35 ms plus chosen margin; qualify power ramps. Do not let firmware override an active trip or automatically recycle power when it cools. A separate pin-correct local-rearm interlock and routed controller/head candidates are now provided in `../thermal/`; their digital checks do not substitute for physical fault tests
3. **One-shot physical interruption:** use a thermally coupled **Sensience MICROTEMP G5-series** line-series thermal fuse; the manufacturer's resistive envelope includes 20 A/277 VAC, unlike a casually chosen 15 A/250 V link. Provisional Tf = 98°C has Th = 83°C and Tm = 410°C; the body is approximately 14.7 × 4.0 mm, with 1.0 mm leads. Exact order variant, the chosen load category, required regional ratings and fuse coordination need supplier confirmation before release. The manufacturer advises keeping continuous operation below Tf −25°C, so Tf98°C is incompatible with a normal 80°C fuse location. A lower trip threshold may be needed after hot-spot testing. [Manufacturer G5 product](https://www.sensience.com/products/microtemp-thermal-fuse-3/), [manufacturer catalog](https://www.sensience.com/wp-content/uploads/2022/12/Microtemp_Catalog.pdf)
4. Mount the thermal fuse against the relevant hottest current-carrying interface through a qualified insulating thermal path, following lead-forming, crimp/weld and heat-sinking instructions. Its metal body is electrically live. Neither a remotely located board sensor nor a software temperature estimate protects a loose socket contact reliably

A thermal latch opening the same relay coil **cannot clear welded load contacts**. The one-shot fuse is a different interruption mechanism but only opens when heat reaches its trigger; an independent rated disconnect/contact mechanism is needed if the requirement is guaranteed removal of output power after a weld at normal temperature. PE remains continuous and unswitched.

## Verification and remaining release holds

Digital checks are in `validation/`:

- All 25 numbered component pins agree between schematic-exported netlist, PCB and manifest; expected no-connects are U1.2, U1.3 and U1.7
- Conservative minimum cross-domain copper separation is **8.795 mm**, including every pad, NC pads, track and via on both copper layers
- A negative control deliberately inserted primary copper closer than 8 mm; the actual KiCad custom rule caught it. Its report is retained, the intentionally invalid board is not
- Final production-candidate ERC/DRC reports are separate from that intentionally failing negative-control report
- Schematic and board-review images are visually inspected; no physical tests or certification tests have run

Remaining holds: complete enclosure/board capture and slot-strength review; insulated harness and strain relief; contamination/altitude/overvoltage-category assumptions; actual PCB CTI/material and applicable product standard; creepage around the entire assembly and wires; surge/EFT/ESD and coordinated protection; resistor hotspot/endurance; 3.3 V logic margins; hot/cold/aged pulse tests; component source authenticity; sensor open/short/power-loss faults; live/neutral reversal/open-neutral/backfeed; snubber leakage and stored energy; real load thermal tests; independent thermal cutout/interlock integration. **Zero digital-rule violations does not close these holds.**

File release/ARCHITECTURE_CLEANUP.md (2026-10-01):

# Canonical ownership cleanup

Current device work preserves one implementation per responsibility:

- The C firmware core owns local safety. The unused Python policy clone was removed after its unique scenarios were retained in the now 42-case C suite and 10,000 fault-priority checks
- The edge owns wire validation, durable SQLite receipts/outbox/inbox, authenticated transport and explicit dispatch gates. Its duplicate forecasting, planning and accounting code/tests were removed after replacement coverage passed in the platform backend
- The platform owns asset/binding ontology, forecasts, policy/approval workflows, interval energy and monetary/carbon accounting. Local device safety remains independent and cannot be overridden by cloud policy
- Device payload schema v2, exact bounded command schema and full calibration v3 are canonical. There is no unverified historical namespace or calibration compatibility shim; no deployed-device migration is assumed, no NVS is erased

## Historical working-tree material

Seventy-nine files (71,972,187 bytes) in `visuals/revA_baseline` were removed after tracing current generators, references and all freeze pins. This directory was a duplicate historical snapshot, not a dependency of the current Rev B source/build pipeline. The current scene, PCB/CAD and source generators remain unchanged by that removal. Git, including pre-cleanup commit `763972e`, retains the historical assets. Seventeen current hardware evidence checks still pass afterward.

Eighteen obsolete integrated electrical validation-history files were likewise removed after consumer tracing; the generator and documentation now use Git history rather than writing new archive snapshots. Active Rev B controller/meter/feedback/thermal module sources and the shared S-expression parser remain because the current integrated-board rebuild reads them. Older source/geometry used by active pipelines is not blindly deleted.

## Safety and verification boundary

The new physical command transport branch is complete code behind independent default-OFF platform and edge gates, matching operator release records and per-device allowlists. No actual physical deployment configuration was enabled. Positive branch tests use inert callbacks; broker tests use explicitly VIRTUAL/SIMULATED endpoints. Firmware actuation remains compiled OFF. None of this qualifies fabrication, calibration, energization or mains safety.

Current digital evidence is in `digital_checks_rev_b.json`, `firmware/validation.json` and the recertification report. Historical PASS records are never substituted for current source hashes or rerun checks.

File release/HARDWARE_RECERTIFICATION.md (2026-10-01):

# Rev B current hardware digital recertification

Date: 2026-09-30. This is evidence for the current mechanical/electrical working tree, not a fabrication, energization, certification or complete system release. Firmware and campus integration have their own evidence.

## Result

The 23 mechanical and 6 electrical stale freeze entries were investigated against the actual pre-migration Git objects, rather than accepted by replacing hashes. Of the 29 files, 24 differed only in project/model identifiers, two additionally removed trailing Markdown whitespace, and three were PDFs. All original SHA-256 values were recovered from Git. The PDFs were regenerated from current sources and their complete 11 pages rendered and visually inspected.

The machine-readable trace is `hardware_recertification.json`. It records original blob IDs, former/current hashes, disposition, current evidence hashes and explicit physical HOLD gates. `hardware_validation_run.txt` preserves the actual current command outputs. No physical CAD or routed PCB design change was necessary.

## Actual checks rerun

- Native KiCad 9.0.2 DRC: 0 violations, 0 unconnected pads, 0 footprint errors; ERC: 0 errors and 0 warnings
- Schematic/main-board pin audit: all 321 numbered main-board keys match; the complete assembly graph covers 348 numbered terminals
- Native supported-rule negative control rejects the synthetic 6 mm domain gap; independent checker rejects a deliberately shifted hot pad
- Fresh separate six-sheet schematic, placement and copper-recipe rebuild passes ERC/DRC and both negative controls. Its physical signature matches the retained PCB: four layers, footprints/pads/nets, all copper items and zone outlines. Generated UUIDs and library nickname/container metadata are not physical comparisons
- Fresh mechanical source build and exports equal retained native geometry at a 1e-10 BRep numeric tolerance: 72 base objects, 72 delivery objects, 235 combined native objects including the nonphysical reservation, and 144 main-board placement/body/lead objects
- Integrated fit, prescribed contact insertion, 11 shutter states, modeled conductive joint connectivity and continuous PE checks reran successfully
- Full insulation-domain audit ran from all current inputs, without incremental reuse: no inputs changed during the run; minimum nominal exposed-primary/main-board separation is 8.516644688 mm against the project-only 8.4 mm screen
- Retained lightweight STEP roundtrip contains 234 valid physical solids. Detailed STEP roundtrip contains 3223 valid solids with relative summed-volume difference 2.12e-8
- Face/polarity drawing, six-sheet schematic and four copper-review pages were regenerated. The source-based drawing snapshot and current preview were refreshed

Fresh reconstruction details and source hashes are in `hardware_geometry_rebuild.json`. Electrical handoff now binds all six schematic sheets, rules, negative controls, source graph and checker scripts, not just the top-level sheet. Mechanical freezing uses the actual rerun reports and source hashes. Validation history remains in Git instead of creating new duplicate working-tree archives.

## Reproduce without physical changes

1. With KiCad 9, FreeCAD 1.0, system pcbnew, Inkscape, ReportLab and pypdf available, copy the checkout into a separate temporary worktree/directory. Keep the Rev B controller/meter/feedback/thermal source modules and `electronics/scripts/sexpr_util.py`; integrated generation still depends on them
2. In that separate copy, run `mechanical/rev_b/build_base.py`, `export_release.py`, `verify_exports.py` with `/usr/bin/python3`; run `electronics/rev_b/integrated/scripts/export_geometry.py --bodies-only`; run `bash electronics/rev_b/integrated/scripts/rebuild.sh --no-geometry`
3. Against the retained checkout, rerun the mechanical integrated-fit, contact, shutter, connectivity, full insulation and export verifiers, including `export_detailed_assembly.py --verify-existing`. Rerun native/independent electrical controls, rear termination and `finalize_validation.py`. Use a writable temporary KiCad/XDG configuration directory
4. Run `/usr/bin/python3 scripts/verify_hardware_rebuild.py --rebuilt-root /path/to/the/separate/copy`. Regenerate and visually review the PDFs if their sources changed
5. Only after those checks pass, refresh `mechanical/rev_b/finalize_snapshot.py`, electrical source hashes, and `scripts/finalize_hardware_handoff.py`. Update the recertification record to the actual run; do not reuse a stale review claim
6. Read-only guards: `python3 -m unittest discover -s tests/hardware -v` and `python3 scripts/validate_hardware_evidence.py`. The latter is also called by `scripts/validate_release_rev_b.py`

## Physical HOLD remains

The 8.5166 mm nominal 3D result is not qualified free-air clearance or creepage. The component-land audit still has an 8.10 mm nominal minimum, and the remote thermal pickup depends on 0.5 mm of unqualified solid insulation. None of these numbers is a standards-compliance result.

No manufacturing, flashing, energization or physical test occurred. Manufactured insulation/PE/dielectric/leakage, 16 A enclosed temperature rise, real load inrush, fault containment, total-clearing fuse coordination, contact force/endurance, materials and mechanical gauges, traceable metrology, thermal response, RF and EMC remain open. See `../docs/ENGINEERING_RELEASE_GATES.md`.

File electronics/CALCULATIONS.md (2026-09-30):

# Preliminary electrical budget and thermal sensitivities

These calculations use declared assumptions and are not measured performance. They establish design questions, not a permissible operating rating.

## Isolated power budget

At an assumed 0.5 A peak controller load on 3.3 V and 85% buck efficiency:

- Buck input: 3.3 × 0.5 / 0.85 = 1.941 W, or 388 mA at 5 V
- Relay coil candidate: 0.403 W, or about 81 mA at 5 V
- Combined: 2.344 W, leaving 0.656 W of a nominal 3 W supply before other loads and temperature derating

A metering isolator, its isolated DC/DC converter, any external sensor and output transients must be added. Measure voltage dips with radio transmission and relay actuation coincident. A supply nameplate margin does not establish stability or enclosure thermal performance.

## Coil driver and status LED

For 81 mA coil current and AO3400A maximum 48 mΩ at 2.5 V gate drive, ideal conduction loss is 0.081² × 0.048 ≈ 0.315 mW at the specified data-sheet conditions. Gate drive is nominally 3.3 V; account for output-level tolerance, temperature and switching transitions. The flyback diode changes relay release time and must be checked against contact arcing and manufacturer guidance.

For a nominal green LED forward voltage of 2.1 V, the 1 kΩ series resistor gives (3.3 − 2.1)/1000 = 1.2 mA. Actual optical intensity, forward voltage and light-guide coupling remain unmeasured.

## Contact-path heating sensitivity

At 16 A, EACH milliohm in a terminal, relay contact, fuse, solder joint, conductor or socket contact dissipates 0.256 W. For illustration:

| Resistance of one interface | Loss at 16 A |
|---|---|
| 1 mΩ | 0.256 W |
| 5 mΩ | 1.28 W |
| 10 mΩ | 2.56 W |

These are sensitivity values, not estimated actual contact resistance. Measure the assembled path with four-wire methods, then validate temperature rise under worst-case contact force, torque, ageing, ambient temperature and enclosure orientation. Summing several interfaces can dominate the electronics' own heat. The thermal fuse must respond to the actual hazardous hot spot, including transfer delay and overshoot.

## Auxiliary fuse inrush question

The PSU's quoted inrush peak does not give pulse energy. An idealized 20 A rectangular pulse lasting 1 ms has I²t = 0.4 A²s; at 5 ms it is 2 A²s. Those examples differ fivefold while sharing the same peak. Use measured worst-case waveforms and the fuse manufacturer's pulse-life guidance, not a peak-only comparison with the 1 A auxiliary fuse.

## Metering sizing

See `METERING_DESIGN.md` for the 0.5 mΩ shunt and voltage-divider example. Their implementation is not present on the current PCB. No stated power, energy, power-factor or load-classification accuracy has been validated in hardware.

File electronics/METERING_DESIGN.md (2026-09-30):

# Metering extension — interface design, NOT fabricated hardware

**Status: critical open gate.** The main controller carries J3; the metering daughterboard is a pin-level candidate architecture only. There is no routed daughterboard, calibration evidence, energy-accuracy claim, or allocated enclosure volume for it. Until it exists and is validated, the socket cannot execute measurement-based load recognition or protection. Never substitute synthetic telemetry as hardware validation.

## Partition

The ADE9153A and its analogue conditioning are **mains referenced** (`GND_HOT`), even though their supply is only 3.3 V. `GND_HOT` must never join `GND_ISO`, protective earth, a debugger, USB or an exposed control. Candidate ADuM3151 separates the SPI domains. Its insulation ratings do not certify this assembly: working voltage, pollution degree, transient category, material group, altitude, package spacing and regulatory applicability require review. A separately qualified isolated power converter is also required; an ordinary common-ground 3.3 V supply defeats the signal barrier.

## Pin contract (mainboard J3)

| J3 | Main net | ADuM3151 controller side | ADuM3151 hot side → ADE9153A |
|---|---|---|---|
| 1 | +3V3_ISO | 1 VDD1 | No direct cross-barrier connection |
| 2 | GND_ISO | 2,10 GND1 | No direct cross-barrier connection |
| 3 | SPI_SCLK | 3 MCLK | 18 SCLK → 31 SCLK |
| 4 | SPI_MOSI | 4 MO | 17 SI → 29 MOSI |
| 5 | SPI_MISO | 5 MI | 16 SO ← 30 MISO |
| 6 | SPI_CS | 6 MSS | 15 SSS → 32 SS |

ADuM3151 hot supply: 20 VDD2 to +3V3_HOT; 11,19 to GND_HOT. Decouple both sides separately. Unused controller inputs 7/8 are held at valid logic; unused outputs 9/13/14 are not connected. Hot input 12 is tied to GND_HOT. Main J3 deliberately omits IRQ and reset: poll meter status; implement local hot-domain reset supervision for ADE pin 28. A later connector revision is required for isolated interrupt and host reset. Begin firmware integration at 1 MHz SPI, then verify timing rather than assuming maximum rates.

## Candidate analogue front end and sizing

A four-terminal **0.5 mΩ shunt** in the switched line path gives 8 mV rms and 0.128 W at 16 A; its sine-wave peak is 11.3 mV. Use Kelvin routing to IAP8/IAN7 through matched anti-alias filters. Pulse energy, temperature coefficient, solder fatigue, short-circuit coordination and overload power must be qualified. A catalog wattage alone is insufficient. Candidate family: Vishay WSK2512 (exact resistance, tolerance and pulse qualification not selected): https://www.vishay.com/en/resistors-fixed/current-sensing/ . A resistive shunt is not an isolating element.

Voltage channel candidate: a 996 kΩ high leg (four 249 kΩ resistors in series) and 1 kΩ lower leg. At 264 V rms this ideal divider produces 0.2648 V rms / 0.3745 V peak; high-leg dissipation is about 70 mW total. This is a sizing calculation, NOT an approved network. Working-voltage/pulse-rated resistors, surge coordination, anti-alias poles, creepage along the series chain and exact common-mode topology require review against ADE9153A's application circuit. Do not connect a simple divider to an arbitrary MCU ADC.

ADE9153A pin planning: current input7/8, voltage14/15, optional CT11/12; grounds1/9/17/20 remain hot; supplies5/24 use 3.3 V hot. Crystal interface3/4; 12.288 MHz reference architecture. Internal outputs2/10/16 and reference18 need their specified local capacitor networks and must not power other devices. mSure network6/13/19/21/22/23 is not fully designed here; standard calibration is the default development path. **Exposed pad must remain floating** per datasheet. No convenient ground thermal pad substitution.

## Production gates

1. Complete hot-domain schematic including power, surge, reset, crystal, reference, analogue filters and all unused-pin treatment
2. Allocate daughterboard envelope or redesign the main PCB; prove barrier clearances in 3D including wiring and fasteners
3. Validate isolation components for actual product standard and continuous working voltage
4. Calibrate against a traceable reference at multiple currents, power factors, temperatures and distorted waveforms; preserve per-unit coefficients with CRC/version
5. Characterize noise and failure detection: unplugged J3, invalid CRC/status, frozen readings, brownout and implausible RMS → reject new automatic commands / hold commissioned state; separately qualified hardware fault protection may interrupt the load
6. No automatic restart after a thermal/electrical fault without explicit, bounded policy and valid sensor recovery

## Primary references, checked 2026-09-30

- ADE9153A Rev0, pin table pp9–10 and application circuit: https://www.analog.com/media/en/technical-documentation/data-sheets/ade9153a.pdf
- ADuM3151/3152/3153 RevC, pin table p13 and insulation information: https://www.analog.com/media/en/technical-documentation/data-sheets/adum3151_3152_3153.pdf

This specification records engineering synthesis. It does not copy the complete manufacturer reference design and has not undergone electrical sign-off.

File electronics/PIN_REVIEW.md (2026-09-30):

# Pin and footprint review record

Digital connectivity check: `validation/net_pin_consistency.json` compares every assigned schematic pin in a KiCad-exported netlist to the PCB pad net. This catches pin-number drift, but it does not certify the circuit.

| Component | Checked implementation | Basis and remaining review |
|---|---|---|
| U1 | ESP32-C3-WROOM-02U; 1=3V3, 2=EN, 9/19=GND; IO4/5/6/7 = SPI; IO10 = relay; IO18/19 = button/LED; IO0/1 = I²C | Installed KiCad symbol/footprint; Espressif module datasheet. Pins 13/14 are therefore unavailable for native USB. External RF connector-axis model still approximate |
| U2 | AP63203WU; 1=FB, 2=EN, 3=IN, 4=GND, 5=SW, 6=BST; TSOT-23-6 | Diodes AP63200-family datasheet and KiCad symbol. Corrected pin map checked in exported netlist. Inductor/capacitor DC bias and switching-loop layout need review |
| Q1 | AO3400A; 1=G, 2=S, 3=D; SOT-23 | AOS official AO3400A datasheet. Guaranteed low-gate drive selection replaces the earlier 2N7002 development candidate |
| D1 | SS14 cathode pad 1 → +5V_ISO; anode pad 2 → COIL_LOW | KiCad SMA footprint and diode symbol. Verify exact vendor marking and coil suppression/release timing |
| K1 | TE RT314005; A1/A2 coil; 11 common; 14 NO; 12 unconnected externally but hazardous L_NC_UNUSED; duplicated high-current pads retain common pin numbers | TE RT1 candidate and KiCad 16 A Form C footprint. Exact production suffix and contact-load category remain approval gates |
| PS1 | Mean Well IRM-03-5; 1=L, 3=N, 14=−V, 16=+V; pad 5 unused | Mean Well IRM-03 datasheet mechanical drawing and native KiCad THT footprint |
| U3 | TMP102AIDRLR; 1=SCL, 2=GND, 3=ALERT, 4=ADD0→GND, 5=V+, 6=SDA | TI TMP102 datasheet and SOT-563. This measures PCB temperature, not a guaranteed socket-contact hot spot |
| J1/J2/J5 | Phoenix MKDS 3/2-5.08 part 1711725; 5.08 mm pitch, 1.3 mm holes; installed height 18 mm | Phoenix current product PDF and matching KiCad MKDS-3 footprint. Current rating depends on wire, temperature and approval category |
| SW1 | OMRON B3F-1000 candidate; duplicate pads 1 form one side, duplicate pads 2 form other; 6 × 6 mm body | Library SW_PUSH_6mm footprint; exact actuator height and manufacturer lead tolerance require independent review |
| LED1 | Kingbright WP710A10GD candidate; 1 cathode, 2 anode; D3.0 mm footprint | Candidate part family; exact optical/mechanical drawing still procurement-review gate |

## Primary sources

- https://www.espressif.com/sites/default/files/documentation/esp32-c3-wroom-02_datasheet_en.pdf
- https://www.diodes.com/datasheet/download/AP63200-AP63201-AP63203-AP63205.pdf
- https://www.aosmd.com/res/data_sheets/AO3400A.pdf
- https://www.meanwell.com/Upload/PDF/IRM-03/IRM-03-SPEC.PDF
- https://www.te.com/en/product-1-1649328-0.html
- https://www.ti.com/lit/ds/symlink/tmp102.pdf
- https://www.phoenixcontact.com/en-gb/products/printed-circuit-board-terminal-mkds-3-2-508-1711725?type=pdf

No board-level current, EMC, isolation, metering or protection test has been performed.

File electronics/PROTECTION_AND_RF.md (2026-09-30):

# Protection and RF candidate integration

Status: real component candidates and nominal geometry selected; application qualification and production sign-off remain open. See the mechanical assembly for allocated pockets and wire-routing envelopes. These parts are external to the main PCB and must be included in the final electrical design, harness drawings and certification bill of materials.

| Ref | Candidate | Geometry / preliminary purpose | Primary source |
|---|---|---|---|
| FH1 | SCHURTER OGN 0031.8201 | THT 22.5 mm pitch; nominal body 25 × 9.6 × 11.5 mm; 4 mm leads. Open holder inside inaccessible enclosure. Do not add a cover without recalculating derating | https://www.schurter.com/en/datasheet/typ_ogn.pdf |
| F_MAIN | Littelfuse 0216016.MXP | 5 × 20 mm ceramic, 16 A fast-acting, 250 VAC candidate. Application current and fault coordination unqualified | https://www.littelfuse.com/assetdocs/littelfuse_fuse_216_datasheet.pdf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 |
| TF1 | Sensience MICROTEMP G5, 110°C candidate | Body 14.7 × Ø4 mm; nominal Ø1 mm leads. G5A01110C ordering suffix requires procurement confirmation; G5 family chosen over 10 A G4. Temperature selection remains provisional | https://www.sensience.com/wp-content/uploads/2022/12/Microtemp_Catalog.pdf |
| F_AUX | Littelfuse 0215001.MXEP | 1 A time-lag 250 VAC, axial ceramic body 21.5 ±1 × Ø5.5 ±0.3 mm; Ø0.65 mm leads, 40 ±1 mm each before forming. Minimum lead bend distance and mounting stand-off per datasheet | https://www.littelfuse.com/~/media/electronics/datasheets/fuses/littelfuse_fuse_215_datasheet.pdf.pdf |
| ANT1 | Taoglas FXP73.07.0100A | Flexible 47 × 7 × 0.1 mm 2.4 GHz antenna, 100 mm 1.13 mm coax, MHF I / U.FL-compatible connector, 2.5 dBi candidate | https://www.taoglas.com/datasheets/FXP73.07.0100A.pdf |

## Electrical order

L blade → F_MAIN → TF1 → protected line junction.

The junction splits into J1.1 (L_FUSED, relay common input) and F_AUX → J5.1 (L_AUX_FUSED, isolated supply input). N blade connects J1.2, J5.2 and J2.2; switched output is K1 NO → J2.1 → socket L contact. PE remains a separate uninterrupted protective path. This description does not validate physical routing, conductor sizes, splices, terminations, fuse supports or any particular fault duty.

The G5 interruption ratings are resistive. A relay weld should leave TF1 capable of interrupting the independently detected contact over-temperature condition, but only if physical coupling, current category, fault current and interruption tests establish that function. Merely mounting TF1 nearby does not establish protection.

## Exact missing data to release protection

- Target outlet standard/jurisdiction, branch circuit type and prospective short-circuit current at the outlet, including upstream protective device time-current and let-through curves
- Maximum continuous current, ambient temperature, local fuse-pocket temperature and orientation; holder derating and fuse self-heating under enclosure conditions
- Load inrush waveform and repetition: peak, pulse width, I²t and locked-rotor / capacitive behavior. The fast 16 A fuse is a first resistive-load candidate, not an approved compressor profile
- PSU input inrush duration/I²t and worst-case cold/hot restart tolerance. A listed 20 A peak alone cannot prove a 1 A time-lag fuse will survive
- Socket contact and plastic allowable temperatures, sensor-to-contact thermal gradient, heat-transfer delay and abnormal-condition overshoot. A provisional 110°C cutoff is not an approved user-accessible or plastic temperature limit
- TF1 insulated attachment method, sleeve properties, lead forming/crimp tooling and solder heat controls; exact suffix and approvals for the final market
- Fuse-interruption approval differences: main 216 series ratings depend on amperage and agency; determine the applicable certificate rather than extrapolating a family headline

## RF gate

ANT1 is connected to U1's existing external RF socket. No PCB RF trace or additional U.FL footprint is required. Mechanical placement along the inside upper wall is a candidate; antenna tape bonding, coax bend radius, strain relief and retention need production review. The coax endpoint is currently an approximate module-envelope coordinate, not vendor-verified connector-axis geometry.

Check Espressif's permitted antenna type/gain and modular approval integration conditions for the selected market. A Taoglas antenna certificate does not certify this end product. Enclosure/contact metal, protective conductors, human proximity and wiring can detune the antenna; measure return loss and radiated performance in the assembled unit. This design contains no infrared emitter or air-conditioner protocol transmitter.

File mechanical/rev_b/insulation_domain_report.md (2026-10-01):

# CARBENTRA CARBENTRA-P16-EVT-B · Insulation-domain proximity audit

**Engineering development only. No electrical insulation or energization approval.**

- Primary source regions: 53
- Source files changed during this audit: 0
- Native filled-zone partitions: 54
- Positive-volume intersections against all target groups: 0 (package/guide overlaps are not automatically electrical shorts)
- Main PCB bottom z11.5; actual native pad/track net names classify domains
- All tabulated distances are nominal Euclidean BRep separation, not qualified clearance or creepage

## Key engineering findings

| Region class | Source | Target | Nominal distance mm |
|---|---|---|---:|
| exposed_primary_to_any_isolated_copper | Blade_L | Track_In2.Cu_2159 [SPI_CS] | 8.5166 |
| exposed_primary_to_isolated_external_copper | Blade_L | Track_B.Cu_447 [+5V_ISO] | 8.7949 |
| bare_link_ends_to_isolated_external_copper | PowerCore_L_RAW__bare_start | Pad_F.Cu_U301_5_4_0 [GND_ISO] | 9.2175 |
| primary_solder_tails_to_isolated_external_copper | MainB_R304_Tail2 [HOT_FB_N_MID] | Pad_F.Cu_PS101_3_2_0 [GND_ISO] | 8.9965 |
| covered_link_core_to_isolated_external_copper | PowerCore_L_RAW__covered | Track_B.Cu_443 [+5V_ISO] | 9.9018 |
| exposed_primary_to_controls | PowerCore_L_PROTECTED__bare_start | LocalButton_GuideOuterEnvelope | 14.6049 |
| exposed_primary_to_case_screw_metal | MainB_F501_FormedLead__1 [HOT_GND] | Screw_0 | 9.5373 |
| exposed_primary_to_RF_routing_reservation | PowerCore_L_FUSE_THERMAL__bare_end | RFServiceSlackEnvelope | 20.2033 |
| covered_link_core_to_RF_routing_reservation | PowerCore_L_FUSE_THERMAL__covered | RFServiceSlackEnvelope | 8.6253 |
| covered_link_core_to_case_screw_metal | PowerCore_L_PROTECTED__covered | Screw_0 | 8.7167 |
| covered_link_core_to_controls | PowerCore_L_PROTECTED__covered | LocalButton_GuideOuterEnvelope | 8.9391 |

The exposed-primary minimum nominally meets the project 8.4 mm geometric screen. This is not a standard-derived acceptance criterion or a tolerance/insulation pass. Internal-layer distances include solid insulation. The thermal coupling is a separate 0.5 mm nominal solid-insulation interface.

Metal-to-metal positive-volume crossings in the checked pairs: 0. No-crossing does not establish safe insulation.

## Smallest pairs by target group

### isolated_external_copper

| Primary region | Target | Distance mm | Overlap mm³ |
|---|---|---:|---:|
| Blade_L | Track_B.Cu_447 [+5V_ISO] | 8.7949 | 0 |
| MainB_R304_Tail2 [HOT_FB_N_MID] | Pad_F.Cu_PS101_3_2_0 [GND_ISO] | 8.9965 | 0 |
| MainB_K101_Tail013 [HOT_NC] | Pad_F.Cu_U301_5_4_0 [GND_ISO] | 9.0540 | 0 |
| PowerCore_L_RAW__bare_start | Pad_F.Cu_U301_5_4_0 [GND_ISO] | 9.2175 | 0 |
| MainB_K101_Tail12 [HOT_NC] | Pad_F.Cu_U202_8_7_0 [GND_ISO] | 9.4613 | 0 |
| PowerCore_L_RAW__covered | Track_B.Cu_443 [+5V_ISO] | 9.9018 | 0 |

### isolated_solder_tails

| Primary region | Target | Distance mm | Overlap mm³ |
|---|---|---:|---:|
| Blade_L | MainB_K101_TailA1 [COIL_5V] | 9.2306 | 0 |
| MainB_R304_Tail2 [HOT_FB_N_MID] | MainB_PS101_Tail3 [GND_ISO] | 9.9947 | 0 |
| PowerCore_L_RAW__bare_start | MainB_K101_TailA1 [COIL_5V] | 10.1260 | 0 |
| PowerCore_L_RAW__covered | MainB_K101_TailA1 [COIL_5V] | 10.5018 | 0 |
| MainB_R303_Tail2 [HOT_FB_AC2] | MainB_PS101_Tail3 [GND_ISO] | 11.4134 | 0 |
| MainB_K101_Tail12 [HOT_NC] | MainB_K101_TailA2 [COIL_LOW] | 14.1600 | 0 |

### isolated_package_envelopes

| Primary region | Target | Distance mm | Overlap mm³ |
|---|---|---:|---:|
| Blade_L | MainB_R305 | 9.1138 | 0 |
| PowerCore_L_RAW__bare_start | MainB_R305 | 9.7418 | 0 |
| MainB_K101_Tail013 [HOT_NC] | MainB_R305 | 10.8809 | 0 |
| PowerCore_L_RAW__covered | MainB_R305 | 11.2196 | 0 |
| MainB_R303_Tail2 [HOT_FB_AC2] | MainB_C107 | 13.0559 | 0 |
| MainB_K101_Tail12 [HOT_NC] | MainB_CI201 | 13.3909 | 0 |

### accessible_controls_and_guide_envelopes

| Primary region | Target | Distance mm | Overlap mm³ |
|---|---|---:|---:|
| PowerCore_L_PROTECTED__covered | LocalButton_GuideOuterEnvelope | 8.9391 | 0 |
| PowerCore_L_PROTECTED__bare_start | LocalButton_GuideOuterEnvelope | 14.6049 | 0 |
| ThermalLead1 | LocalButton_GuideOuterEnvelope | 15.7205 | 0 |
| ThermalBody | LocalButton_GuideOuterEnvelope | 18.8751 | 0 |
| Contact_L | LocalButton_GuideOuterEnvelope | 18.9823 | 0 |
| PowerCore_L_OUTPUT__bare_end | LocalButton_GuideOuterEnvelope | 20.9823 | 0 |

### accessible_case_screws

| Primary region | Target | Distance mm | Overlap mm³ |
|---|---|---:|---:|
| PowerCore_L_PROTECTED__covered | Screw_0 | 8.7167 | 0 |
| MainB_F501_FormedLead__1 [HOT_GND] | Screw_0 | 9.5373 | 0 |
| MainB_PS101_Tail1 [HOT_N] | Screw_1 | 9.9434 | 0 |
| PowerCore_L_FUSE_THERMAL__covered | Screw_1 | 12.4602 | 0 |
| PowerCore_L_RAW__covered | Screw_0 | 14.4303 | 0 |
| PowerCore_L_FUSE_THERMAL__bare_start | Screw_1 | 14.8114 | 0 |

### rf_service_loop_reservation

| Primary region | Target | Distance mm | Overlap mm³ |
|---|---|---:|---:|
| PowerCore_L_FUSE_THERMAL__covered | RFServiceSlackEnvelope | 8.6253 | 0 |
| PowerCore_L_FUSE_THERMAL__bare_end | RFServiceSlackEnvelope | 20.2033 | 0 |
| ThermalLead2 | RFServiceSlackEnvelope | 21.2863 | 0 |
| ThermalBody | RFServiceSlackEnvelope | 25.5945 | 0 |
| Contact_L | RFServiceSlackEnvelope | 27.2576 | 0 |
| Contact_N | RFServiceSlackEnvelope | 39.1581 | 0 |

### isolated_internal_copper

| Primary region | Target | Distance mm | Overlap mm³ |
|---|---|---:|---:|
| Blade_L | Track_In2.Cu_2159 [SPI_CS] | 8.5166 | 0 |
| MainB_R304_Tail2 [HOT_FB_N_MID] | Pad_In1.Cu_PS101_3_2_0 [GND_ISO] | 8.9965 | 0 |
| PowerCore_L_RAW__bare_start | Track_In2.Cu_2159 [SPI_CS] | 9.0283 | 0 |
| PowerCore_L_RAW__covered | Track_In2.Cu_2159 [SPI_CS] | 9.3294 | 0 |
| MainB_R303_Tail2 [HOT_FB_AC2] | Track_In1.Cu_1063 [GND_ISO] | 10.2067 | 0 |
| MainB_K101_Tail12 [HOT_NC] | FilledZone_In2.Cu_4_cell_60_60_0 [GND_ISO] | 10.4454 | 0 |

### mixed_domain_package_envelopes

| Primary region | Target | Distance mm | Overlap mm³ |
|---|---|---:|---:|
| MainB_PS101_Tail1 [HOT_N] | MainB_PS101 | 0.0000 | 0 |
| MainB_PS101_Tail2 [HOT_AUX_FUSED] | MainB_PS101 | 0.0000 | 0 |
| MainB_K101_Tail11 [HOT_LOAD] | MainB_K101 | 0.0000 | 0 |
| MainB_K101_Tail012 [HOT_LOAD] | MainB_K101 | 0.0000 | 0 |
| MainB_K101_Tail12 [HOT_NC] | MainB_K101 | 0.0000 | 0 |
| MainB_K101_Tail013 [HOT_NC] | MainB_K101 | 0.0000 | 0 |

### remote_sensor_assembly

| Primary region | Target | Distance mm | Overlap mm³ |
|---|---|---:|---:|
| Contact_L | RemoteHead_assembled_all_solids | 0.5000 | 0 |
| ThermalBody | RemoteHead_assembled_all_solids | 5.5350 | 0 |
| ThermalLead1 | RemoteHead_assembled_all_solids | 7.1366 | 0 |
| ThermalLead2 | RemoteHead_assembled_all_solids | 7.1366 | 0 |
| Contact_N | RemoteHead_assembled_all_solids | 8.4065 | 0 |
| PowerCore_L_FUSE_THERMAL__bare_end | RemoteHead_assembled_all_solids | 8.8717 | 0 |

## Thermal-pickup interface

| Member | Distance to world-placed isolated head, mm |
|---|---:|
| Contact_L | 0.5000 |
| ThermalPad | 0.0000 |
| ThermalBody | 5.5350 |
| ThermalLead1 | 7.1366 |
| ThermalLead2 | 7.1366 |

Nominal0.5mm thermal pad intentionally separates primary pickup and isolated head. Solid-insulation material/system qualification remains OPEN.

## Positive-volume intersections

No positive-volume intersections were found in these tested pairs. This does not prove electrical separation, safe access, or compliant solid insulation.

## Interpretation and open gates

- All distances are direct Euclidean geometry, not a solved free-air path or surface creepage path. Plastic may lie between nearest points.
- Six covered links have1mm nominal carrier wall,0.2mm nominal radial copper-to-carrier bore gap and unqualified resin/joints. Proximity through that plastic is not an8mm air-gap pass.
- Thermal pad0.5mm is an intentional primary/isolated solid-insulation interface, not certified insulation.
- Component envelopes use nominal/max vendor dimensions or F.Fab rectangles, not manufacturer detailed CAD. lead_reserve geometries are conservative pin reservations.
- Copper z/thickness are visualization inputs(.07outer/.035inner), not a released layer stack. Via columns are conservative annular envelopes.
- Internal tracks/pads and native filled GND_ISO plane polygons are included in internal-copper results. Filled polygons are partitioned using exact KiCad integer clipping. Internal-layer separation is solid insulation, not an air-clearance result. Native PCB DRC remains necessary.
- Accessible pusher and guide-envelope distances are to insulating geometry, not standardized access probes or touchable metal.
- RFServiceSlackEnvelope is non-physical reference geometry, excluded from physical part count/mass; distances to it are conservative routing-reservation distances, not actual coax-shield clearance. About44mm service-loop allocation assumesR>=6mm/loopR~7mm; vendor bend and strain relief remain unqualified.
- Four case screws are modeled metallic major/shaft/head envelopes; distance to an embedded shaft is not a certified touch path. Boss plastic and partial-withdrawal access require review.
- ThermalBody is conservatively treated as a potentially-primary metal/body envelope until its exact construction and insulation status are qualified; it is separate from the actual exposed TF1 lead solids.
- No tolerance, warpage, contamination, material CTI, impulse, working-voltage, dielectric, thermal, spring-force or fault-withstand qualification.
- Source CAD is opened read-only and not recomputed/saved; exposed-link segmentation is reconstructed from current power_links.py. Input hash consistency is reported.

## Evidence and repeatability

Run `/usr/bin/python3 mechanical/rev_b/insulation_domain_audit.py` from the repository. Full source hashes, exact closest-point coordinates, per-region minima and lead/pad assignments are in `insulation_domain_report.json`. No source geometry is modified.

Primary references: [GB1002-2024 official record](https://openstd.samr.gov.cn/bzgk/std/newGbInfo?hcno=F8C9E208891B7BB5AF1B3E64933693C2), [SHF fuse](https://www.schurter.com/en/datasheet/typ_SHF_6.3x32.pdf), [CQP clips](https://www.schurter.com/en/datasheet/typ_CQP.pdf). These sources do not certify the custom assembly.

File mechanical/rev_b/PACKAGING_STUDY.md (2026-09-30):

# CARBENTRA-P16 Rev B · 集成封装研究（尚未冻结）

Rev A 文件不变。Rev B 不采用四块完整实验板简单堆叠后扩大外壳的路线；电子组正在把计量、隔离、独立热保护和输出反馈整合进主板。以下是给 PCB 布局的机械约束，不是最终装配证明。

## 候选尺寸与空间

- 外壳候选108×93×65mm，外轮廓R14，标称壁厚2.4
- 主板候选100×85×1.6mm，必须R10圆角（或等效切角）；方角会穿入壳体圆角
- PCB安装孔候选(±44,±36)，D3.2；电子组需核实孔周围禁布区
- PCB底面z11，顶面z12.6，零件包络上限23，最高点z35.6
- 5mm长的端子焊脚从板顶伸到z7.6；背板内面z3，形成4.6mm后侧空间。必须以真实引脚体积检查线束，不能只检验元件上面的盒子
- 插接载体主空间z41–57；PCB元件包络顶到载体底有5.4mm。实际过线必须逐条验证，不把这层当成无条件可用的平面
- 前部两侧可容纳已选保险丝座、热切断器与固定结构；其保留空间不得被主板元件提前占用

曾考虑132×108×72–78mm、右侧竖置计量板和左侧竖置保护板，因体积接近1L且属于包装现有实验模块而非结构优化，未制作成最终外壳。

## 热传感器实际耦合

传感头12×12mm需与插套/端子热点通过电绝缘导热界面联系。当前TMP302封装高0.6mm，而原竖直排针高8.38mm，会侵入附近插接空间；需要低矮侧出线、合适锁定连接器或有固定与应力释放的线束端接方案。

可评估KERATHERM86/60、0.5mm导热绝缘片作为机械候选。厂家2026年目录列出4.5W/(m·K)、厚度范围0.25–0.5mm，并列出在0.25mm样品条件下的5.0kVAC材料击穿数据。该材料数据不是本产品的加强绝缘认证，也不是长期工作电压或允许间隙。需设计防位移/防切穿支承，核实压缩、爬电路径、耐压和真实热滞后。

来源：Kerafol2026目录，纸面48页/PDF第25页：
https://www.kerafol.com/wp-content/uploads/2026/05/Kerafol_Katalog_Keratherm_Web_06-26.pdf

## 墙面插装的重量与力矩

实际质量尚不能从外形或占位包络当成测量值。初期风险分析暂用250–400g总质量、重心离安装面30–45mm的假设区间：静力矩m·g·e约0.074–0.177N·m，仅含设备自身重量，不含外接插头、垂挂电缆或牵拉力。

最终应由材料密度和实际BOM做质量预算，再实测重心、插拔保持力、旋转趋势、墙面插座安装强度及线缆牵拉工况。软垫或外壳接触面只能在实际配套墙插上验证，不应被当成已经有效的防倾倒固定件。标准插脚量规仍需按GB1002-2024核实。

## 必须形成的最终检查

1. 实际PCB、元件包络、焊脚及线束共同坐标装配
2. 每对部件的实体干涉与被明确标识的预期导电/机械接触
3. 三个临时插脚扫掠空间及保护门运动空间
4. 传感头、导热片与接触件的无短路耦合路径
5. 板件独立固定、线束应力释放、保护件保持与按钮导向
6. 明确区分几何适配、工程计算、真实试验与尚未取得的认证

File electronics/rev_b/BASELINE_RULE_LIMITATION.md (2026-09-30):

# Frozen EVT-A rule limitation

The EVT-A files remain unchanged for traceability. During CARBENTRA EVT-B review, a reproducible negative control demonstrated that JavaScript-style `NetName.startsWith(...)` expressions in KiCad custom rules did not enforce the intended net-prefix constraints. A generic native DRC count of zero therefore does not prove those particular domain rules were evaluated.

EVT-B integrated rules use supported `NetName == 'HOT_*'` wildcard comparisons with explicit symmetric conditions. Native negative controls and an independent all-layer projected-copper audit are retained under `integrated/validation/rule_controls/`. The modular B metering reference was corrected and rerun with zero violations and zero unconnected items. Controller rules use explicit net names; feedback uses explicit net classes and its independent negative control.

This note does not upgrade or requalify EVT-A. Neither revision is authorized for fabrication or energization by its digital check results. Manufacturing insulation, component tolerances, high-current heating, protection coordination and physical safety tests remain separate release gates.

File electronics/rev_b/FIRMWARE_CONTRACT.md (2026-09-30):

# Rev B metering firmware contract

Engineering contract; no flashed-hardware or calibrated accuracy claim.

## Electrical interface

JISO: 1 ISO_3V3, 2 ISO_GND, 3 SCLK (GPIO4), 4 MOSI (GPIO6), 5 MISO (GPIO5), 6 CS (GPIO7), 7 ISO_5V, 8 ISO_GND. ISO6741DWR separates every SPI signal; R05CT05S supplies the line-referenced 3.3 V domain. No direct hot-domain debugger.

Use 100 kHz, MSB first, SPI mode 3; validate timing on isolated-side logic analyzer only. Never infer link integrity from plausible numeric readings alone. No fabricated calibration coefficients are allowed.

## Verified ATM90E26 facts

Source: [Microchip datasheet](https://ww1.microchip.com/downloads/aemDocuments/documents/OTH/ProductDocuments/DataSheets/Atmel-46002-SE-M90E26-Datasheet.pdf), sections 4, 5, 6.2.
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

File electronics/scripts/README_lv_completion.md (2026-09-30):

# Fixed-placement LV copper completion

The deliverable is `../candidate_lv.kicad_pcb`, with matching project and rule files.
The final actual KiCad report is `../validation/candidate_lv_drc.rpt`:

- 0 design-rule violations
- 0 low-voltage unconnected items
- 9 intentionally open mains-domain connections, including the two normally-closed relay contacts on `L_NC_UNUSED`
- 0 footprint errors reported
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

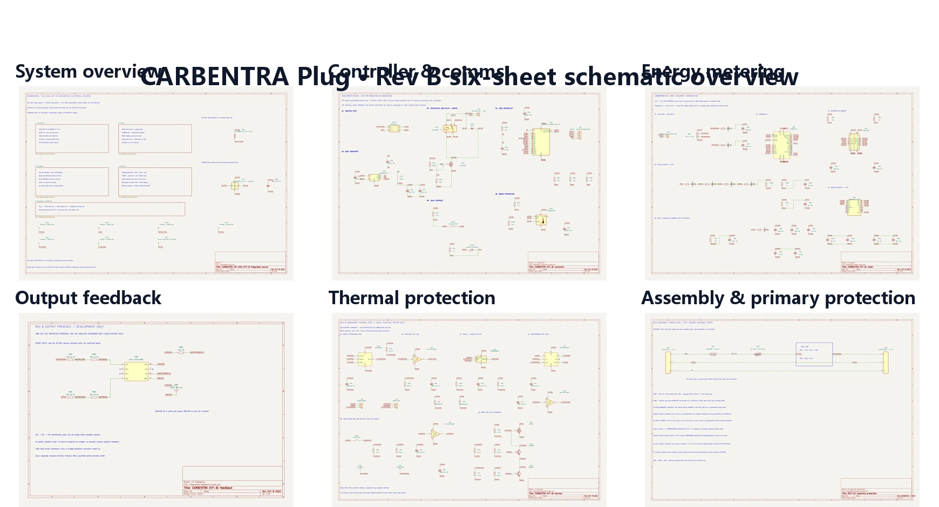
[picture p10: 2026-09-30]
docs/assets/readme/schematic-overview.webp

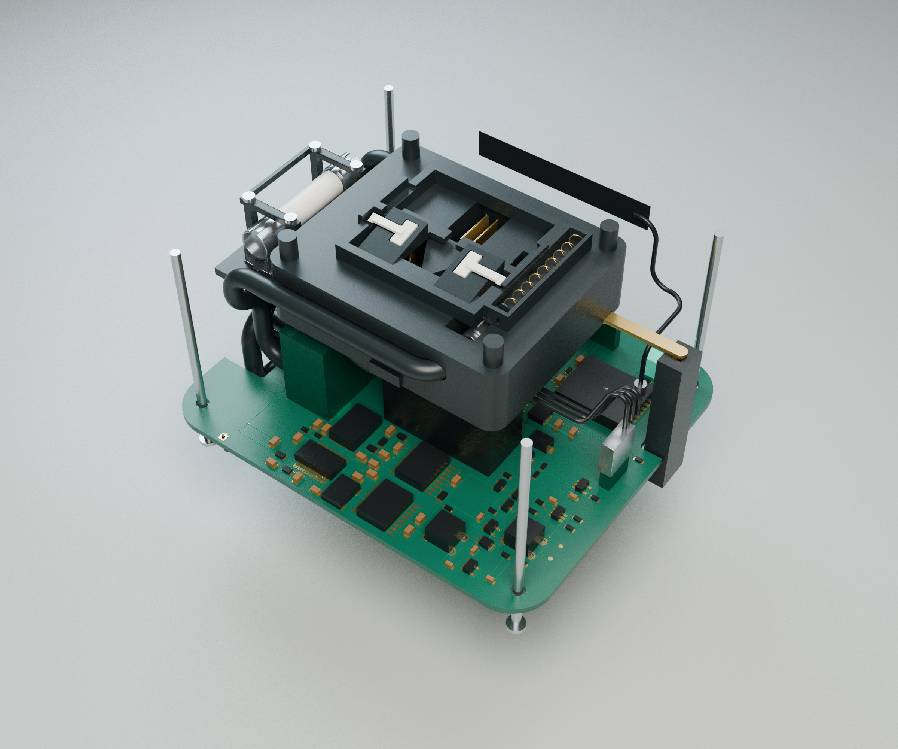
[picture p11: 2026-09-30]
visuals/rev_b/renders/04_internal_architecture.png

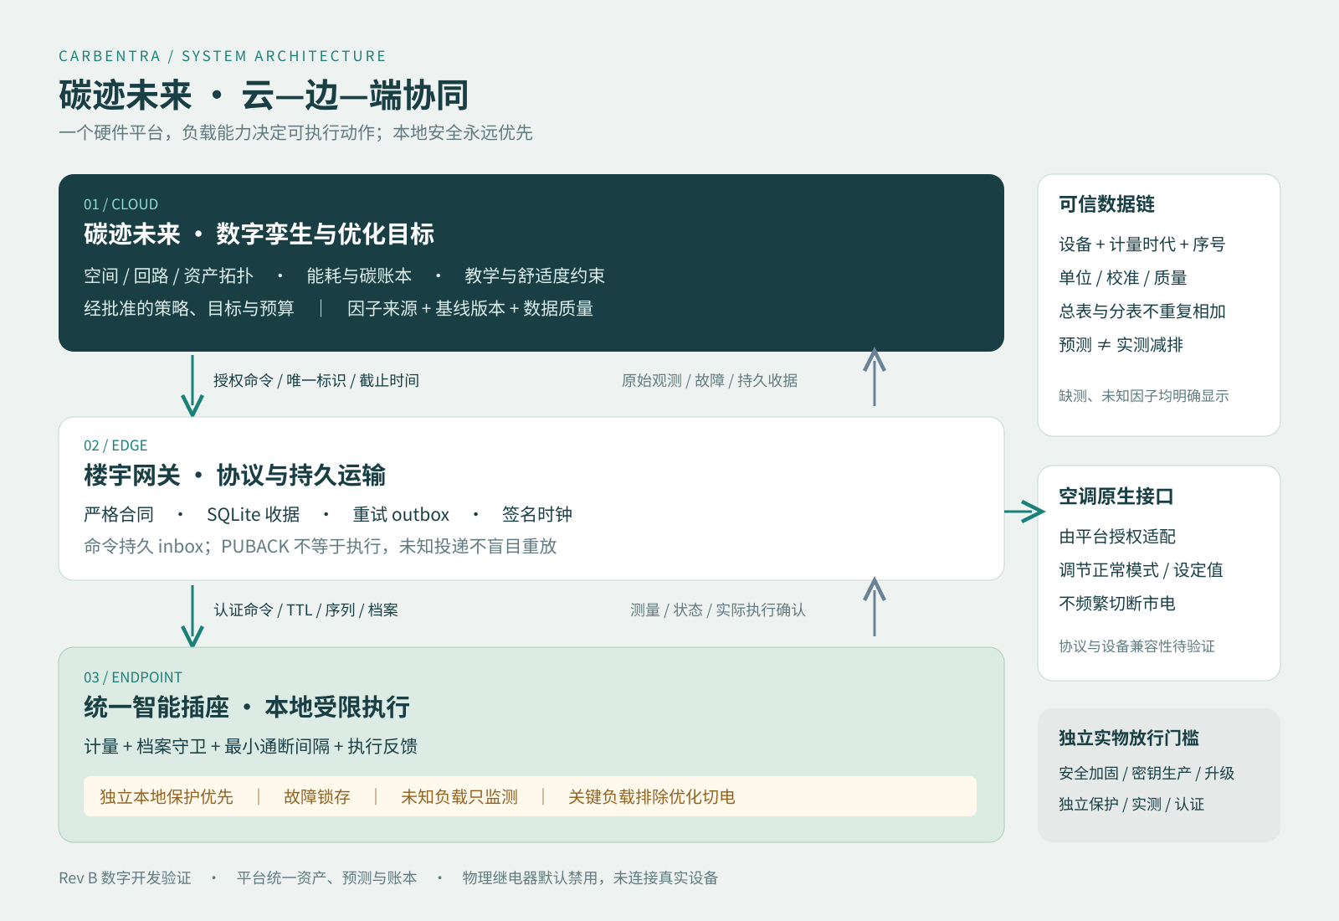
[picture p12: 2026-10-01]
docs/system/cloud-edge-end-architecture.png

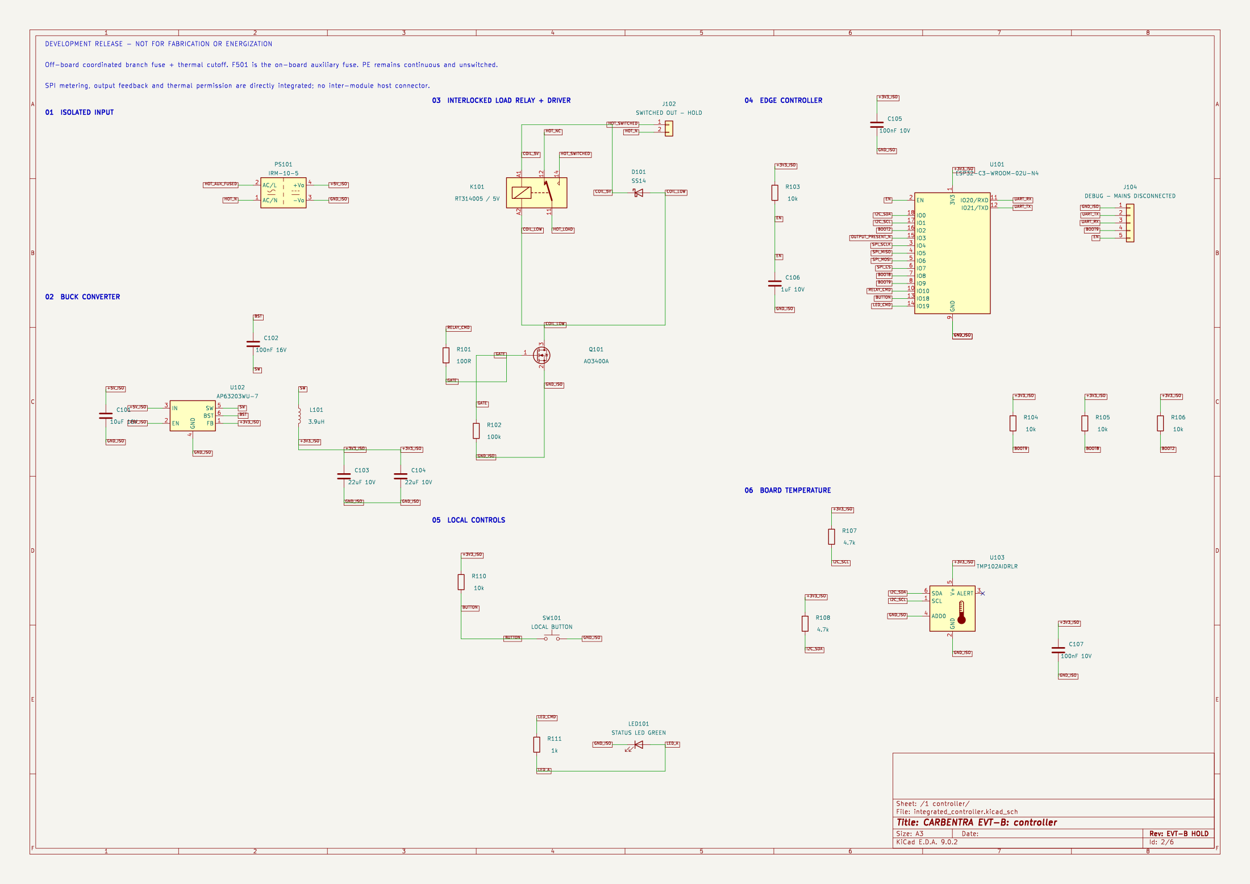
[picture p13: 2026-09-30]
electronics/rev_b/integrated/exports/integrated-1 controller.png

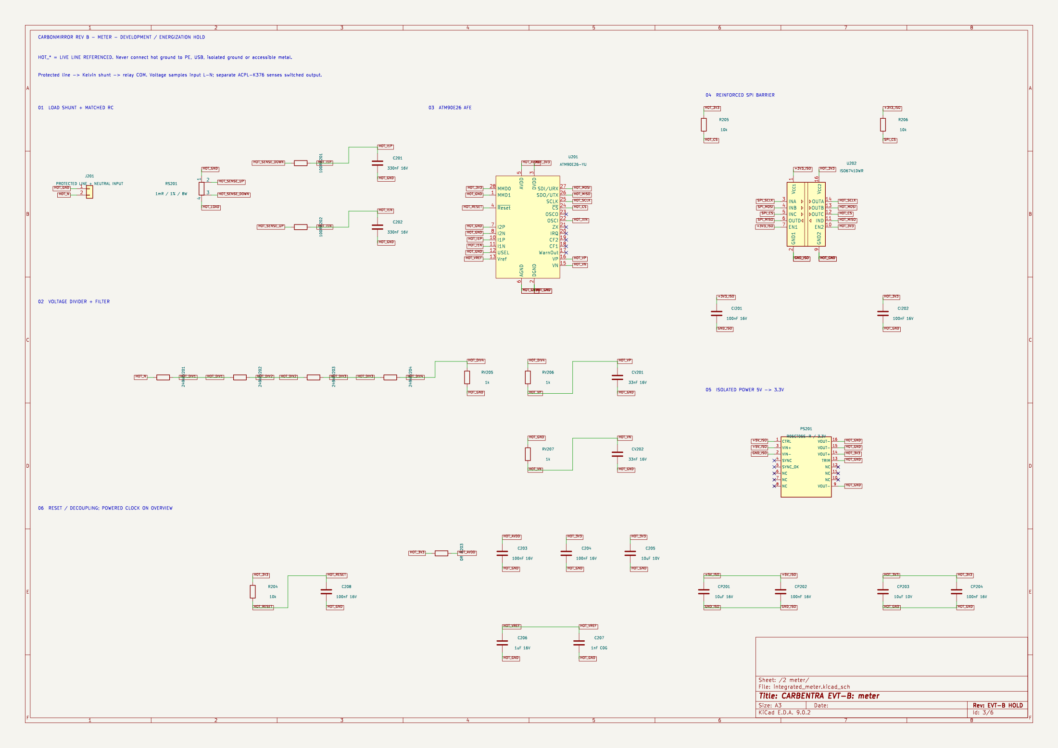
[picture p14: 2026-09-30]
electronics/rev_b/integrated/exports/integrated-2 meter.png

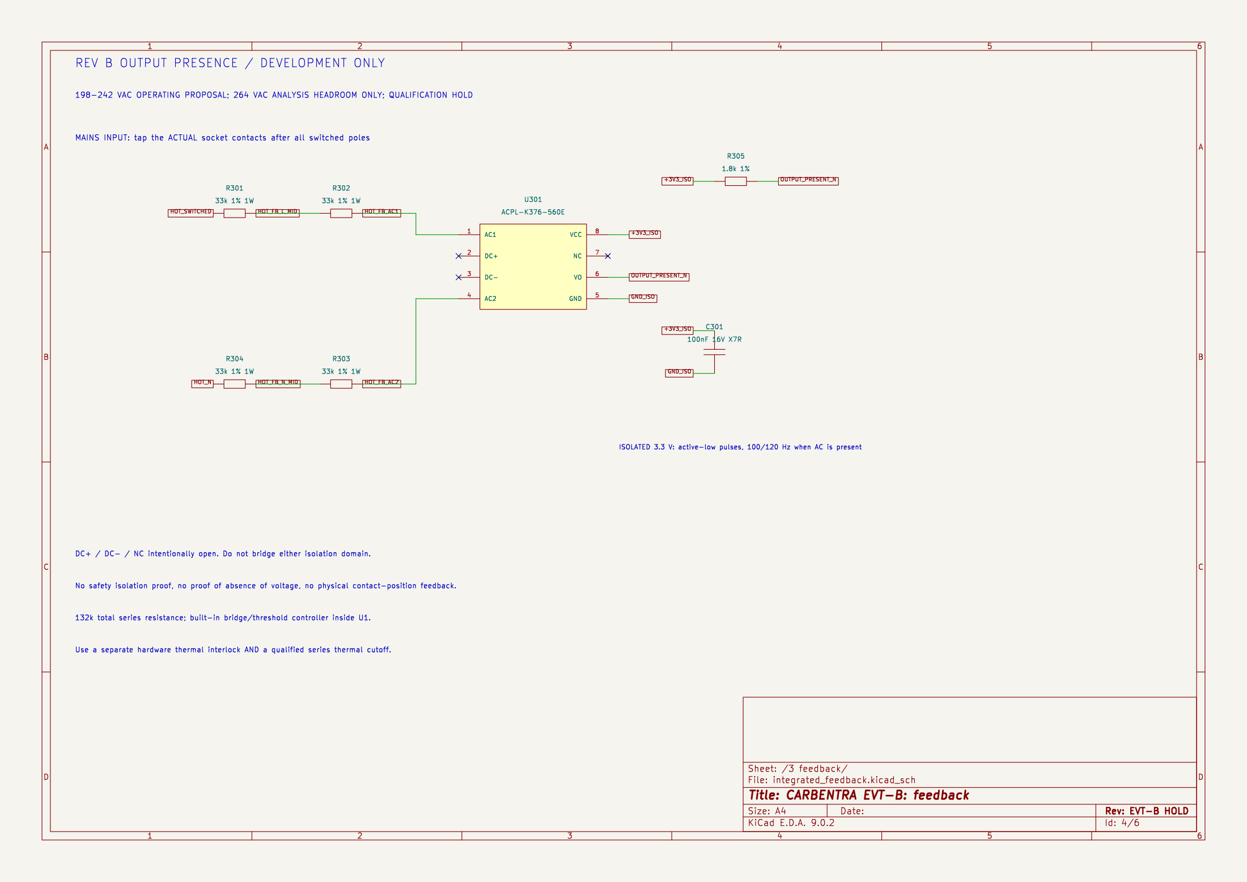
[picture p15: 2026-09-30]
electronics/rev_b/integrated/exports/integrated-3 feedback.png

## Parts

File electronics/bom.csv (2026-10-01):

Reference | Value | Manufacturer part candidate | Footprint | Source URL | Status
PS1 | IRM-03-5 | IRM-03-5 | Converter_ACDC:Converter_ACDC_MeanWell_IRM-03-xx_THT | https://www.meanwell.com/Upload/PDF/IRM-03/IRM-03-SPEC.PDF | UNRELEASED: verify exact variant, sourcing and application
K1 | RT314005 / 5V | RT314005 / 1-1649328-0 | Relay_THT:Relay_SPDT_Schrack-RT1-16A-FormC_RM5mm | https://www.te.com/en/product-1-1649328-0.html | UNRELEASED: verify exact variant, sourcing and application
U1 | ESP32-C3-WROOM-02U-N4 | ESP32-C3-WROOM-02U-N4 | RF_Module:ESP32-C3-WROOM-02U | https://www.espressif.com/sites/default/files/documentation/esp32-c3-wroom-02_datasheet_en.pdf | UNRELEASED: verify exact variant, sourcing and application
U2 | AP63203WU-7 | AP63203WU-7 | Package_TO_SOT_SMD:TSOT-23-6 | https://www.diodes.com/datasheet/download/AP63200-AP63201-AP63203-AP63205.pdf | UNRELEASED: verify exact variant, sourcing and application
L1 | 3.9uH | SRN4018-3R9M | Inductor_SMD:L_Bourns-SRN4018 | https://www.bourns.com/docs/product-datasheets/srn4018.pdf | UNRELEASED: verify exact variant, sourcing and application
C1 | 10uF 16V | GRM21-series candidate | Capacitor_SMD:C_0805_2012Metric | https://www.murata.com/en-us/products/capacitor/ceramiccapacitor | UNRELEASED: verify exact variant, sourcing and application
C2 | 100nF 16V | GRM21-series candidate | Capacitor_SMD:C_0805_2012Metric | https://www.murata.com/en-us/products/capacitor/ceramiccapacitor | UNRELEASED: verify exact variant, sourcing and application
C3 | 22uF 10V | GRM21-series candidate | Capacitor_SMD:C_0805_2012Metric | https://www.murata.com/en-us/products/capacitor/ceramiccapacitor | UNRELEASED: verify exact variant, sourcing and application
C4 | 22uF 10V | GRM21-series candidate | Capacitor_SMD:C_0805_2012Metric | https://www.murata.com/en-us/products/capacitor/ceramiccapacitor | UNRELEASED: verify exact variant, sourcing and application
C5 | 100nF 10V | GRM21-series candidate | Capacitor_SMD:C_0805_2012Metric | https://www.murata.com/en-us/products/capacitor/ceramiccapacitor | UNRELEASED: verify exact variant, sourcing and application
Q1 | AO3400A | AO3400A | Package_TO_SOT_SMD:SOT-23 | https://www.aosmd.com/res/data_sheets/AO3400A.pdf | UNRELEASED: verify exact variant, sourcing and application
D1 | SS14 | SS14 | Diode_SMD:D_SMA | https://www.vishay.com/docs/88746/ss12.pdf | UNRELEASED: verify exact variant, sourcing and application
R1 | 100R | RC0603FR-07100RL | Resistor_SMD:R_0603_1608Metric | https://www.yageo.com/en/ProductSearch | UNRELEASED: verify exact variant, sourcing and application
R2 | 100k | RC0603FR-07100KL | Resistor_SMD:R_0603_1608Metric | https://www.yageo.com/en/ProductSearch | UNRELEASED: verify exact variant, sourcing and application
R3 | 10k | RC0603FR-0710KL | Resistor_SMD:R_0603_1608Metric | https://www.yageo.com/en/ProductSearch | UNRELEASED: verify exact variant, sourcing and application
C6 | 1uF 10V | GRM21-series candidate | Capacitor_SMD:C_0805_2012Metric | https://www.murata.com/en-us/products/capacitor/ceramiccapacitor | UNRELEASED: verify exact variant, sourcing and application
R4 | 10k | RC0603FR-0710KL | Resistor_SMD:R_0603_1608Metric | https://www.yageo.com/en/ProductSearch | UNRELEASED: verify exact variant, sourcing and application
R5 | 10k | RC0603FR-0710KL | Resistor_SMD:R_0603_1608Metric | https://www.yageo.com/en/ProductSearch | UNRELEASED: verify exact variant, sourcing and application
R6 | 10k | RC0603FR-0710KL | Resistor_SMD:R_0603_1608Metric | https://www.yageo.com/en/ProductSearch | UNRELEASED: verify exact variant, sourcing and application
U3 | TMP102AIDRLR | TMP102AIDRLR | Package_TO_SOT_SMD:SOT-563 | https://www.ti.com/lit/ds/symlink/tmp102.pdf | UNRELEASED: verify exact variant, sourcing and application
R7 | 4.7k | RC0603FR-074K7L | Resistor_SMD:R_0603_1608Metric | https://www.yageo.com/en/ProductSearch | UNRELEASED: verify exact variant, sourcing and application
R8 | 4.7k | RC0603FR-074K7L | Resistor_SMD:R_0603_1608Metric | https://www.yageo.com/en/ProductSearch | UNRELEASED: verify exact variant, sourcing and application
R9 | 10k | RC0603FR-0710KL | Resistor_SMD:R_0603_1608Metric | https://www.yageo.com/en/ProductSearch | UNRELEASED: verify exact variant, sourcing and application
C7 | 100nF 10V | GRM21-series candidate | Capacitor_SMD:C_0805_2012Metric | https://www.murata.com/en-us/products/capacitor/ceramiccapacitor | UNRELEASED: verify exact variant, sourcing and application
J1 | LINE IN - terminal HOLD | 1711725 | TerminalBlock_Phoenix:TerminalBlock_Phoenix_MKDS-3-2-5.08_1x02_P5.08mm_Horizontal | https://www.phoenixcontact.com/en-pc/products/pcb-terminal-block-mkds-3-2-508-1711725 | UNRELEASED: verify exact variant, sourcing and application
J2 | SWITCHED OUT - HOLD | 1711725 | TerminalBlock_Phoenix:TerminalBlock_Phoenix_MKDS-3-2-5.08_1x02_P5.08mm_Horizontal | https://www.phoenixcontact.com/en-pc/products/pcb-terminal-block-mkds-3-2-508-1711725 | UNRELEASED: verify exact variant, sourcing and application
J3 | ISOLATED METER PORT | Samtec TSW-1xx-07 candidate | Connector_PinHeader_2.54mm:PinHeader_1x06_P2.54mm_Vertical | https://www.samtec.com/products/tsw | UNRELEASED: verify exact variant, sourcing and application
J4 | DEBUG - MAINS DISCONNECTED | Samtec TSW-1xx-07 candidate | Connector_PinHeader_2.54mm:PinHeader_1x05_P2.54mm_Vertical | https://www.samtec.com/products/tsw | UNRELEASED: verify exact variant, sourcing and application
J5 | FUSED AUXILIARY INPUT | 1711725 | TerminalBlock_Phoenix:TerminalBlock_Phoenix_MKDS-3-2-5.08_1x02_P5.08mm_Horizontal | https://www.phoenixcontact.com/en-pc/products/pcb-terminal-block-mkds-3-2-508-1711725 | UNRELEASED: verify exact variant, sourcing and application
SW1 | LOCAL BUTTON | B3F-1000 candidate | Button_Switch_THT:SW_PUSH_6mm | https://components.omron.com/us-en/products/switches/B3F | UNRELEASED: verify exact variant, sourcing and application
LED1 | STATUS LED GREEN | WP710A10GD candidate | LED_THT:LED_D3.0mm | https://www.kingbrightusa.com/ | UNRELEASED: verify exact variant, sourcing and application
R10 | 10k | RC0603FR-0710KL | Resistor_SMD:R_0603_1608Metric | https://www.yageo.com/en/ProductSearch | UNRELEASED: verify exact variant, sourcing and application
R11 | 1k | RC0603FR-071KL | Resistor_SMD:R_0603_1608Metric | https://www.yageo.com/en/ProductSearch | UNRELEASED: verify exact variant, sourcing and application

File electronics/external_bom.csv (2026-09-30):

Reference | Manufacturer | Part candidate | Status | Source
FH1 | SCHURTER | 0031.8201 | Holder selected for nominal geometry; thermal derating unqualified | https://www.schurter.com/en/datasheet/typ_ogn.pdf
F_MAIN | Littelfuse | 0216016.MXP | 16 A fast 250 VAC development candidate; load and fault coordination open | https://www.littelfuse.com/assetdocs/littelfuse_fuse_216_datasheet.pdf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
TF1 | Sensience | MICROTEMP G5 110C / G5A01110C candidate | Family and nominal envelope verified; ordering suffix and trip temperature require confirmation | https://www.sensience.com/wp-content/uploads/2022/12/Microtemp_Catalog.pdf
F_AUX | Littelfuse | 0215001.MXEP | 1 A time lag 250 VAC candidate; PS1 inrush coordination open | https://www.littelfuse.com/~/media/electronics/datasheets/fuses/littelfuse_fuse_215_datasheet.pdf.pdf
ANT1 | Taoglas | FXP73.07.0100A | Geometry selected; module approval and assembled RF tuning open | https://www.taoglas.com/datasheets/FXP73.07.0100A.pdf
METER_IC | Analog Devices | ADE9153A | Architecture candidate only; no daughterboard implemented | https://www.analog.com/media/en/technical-documentation/data-sheets/ade9153a.pdf
METER_ISOLATOR | Analog Devices | ADuM3151 | Architecture candidate only; no daughterboard implemented | https://www.analog.com/media/en/technical-documentation/data-sheets/adum3151_3152_3153.pdf

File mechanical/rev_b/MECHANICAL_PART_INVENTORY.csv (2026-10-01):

CAD_ID | Description | Assembly_group | Material_or_envelope | Volume_mm3 | Solid_count | Status
RearShell | Rear housing with PCB and fuse supports | rear | PC-FR insulating resin candidate | 78790.588794 | 1 | Engineering development; no production or energizing release
FrontLid | Front housing with button/LED guides | front | PC-FR insulating resin candidate | 35891.41188 | 1 | Engineering development; no production or energizing release
SeamRing | SeamRing | front | PC-FR insulating resin candidate | 255.593093 | 1 | Engineering development; no production or energizing release
RearFinish | RearFinish | rear | PC-FR insulating resin candidate | 36.296665 | 1 | Engineering development; no production or energizing release
Carrier | Insulating contact and thermal-pickup carrier | contact_carrier | PC-FR insulating resin candidate | 37989.951689 | 1 | Engineering development; no production or energizing release
ThermalPad | 0.5 mm isolated sensor pickup pad | thermal | PC-FR insulating resin candidate | 359.68 | 1 | Engineering development; no production or energizing release
PEChannel | Retained protective-earth routing channel | contact_carrier | PC-FR insulating resin candidate | 1656.629589 | 1 | Engineering development; no production or energizing release
PEBus | Continuous protective-earth copper link | contact_carrier | Cu-ETP candidate; forming/joint qualification pending | 414.574846 | 1 | Engineering development; no production or energizing release
ShutterGuide | ShutterGuide | shutter | PC-FR insulating resin candidate | 1345.808137 | 1 | Engineering development; no production or energizing release
ShutterSlider | ShutterSlider | shutter | PC-FR insulating resin candidate | 685.500148 | 1 | Engineering development; no production or energizing release
Pawl_L | Left mechanical pawl at N aperture | shutter | PC-FR insulating resin candidate | 29.966173 | 1 | Engineering development; no production or energizing release
Pawl_N | Right mechanical pawl at L aperture | shutter | PC-FR insulating resin candidate | 29.966173 | 1 | Engineering development; no production or energizing release
PawlSpring_L | PawlSpring_L | shutter | Spring/fastener metal candidate | 0.238793 | 1 | Engineering development; no production or energizing release
PawlSpring_N | PawlSpring_N | shutter | Spring/fastener metal candidate | 0.238793 | 1 | Engineering development; no production or energizing release
ShutterReturnSpring | ShutterReturnSpring | shutter | Spring/fastener metal candidate | 3.515902 | 1 | Engineering development; no production or energizing release
LocalButton | Local operating-button plunger | front | PC-FR insulating resin candidate | 435.726335 | 1 | Engineering development; no production or energizing release
RearmButton | Recessed independent thermal-latch rearm plunger | front | PC-FR insulating resin candidate | 341.101564 | 1 | Engineering development; no production or energizing release
StatusLightGuide | Status LED optical guide | front | Optical PC candidate | 210.813433 | 1 | Engineering development; no production or energizing release
BladeSleeve_L | BladeSleeve_L | rear | PC-FR insulating resin candidate | 50.22 | 1 | Engineering development; no production or energizing release
BladeSleeve_N | BladeSleeve_N | rear | PC-FR insulating resin candidate | 50.22 | 1 | Engineering development; no production or energizing release
Blade_L | Blade_L | rear | Conductive copper-alloy rear-blade candidate; interface and joint qualification pending | 316.54 | 1 | Engineering development; no production or energizing release
Blade_N | Blade_N | rear | Conductive copper-alloy rear-blade candidate; interface and joint qualification pending | 305.355402 | 1 | Engineering development; no production or energizing release
Blade_PE | Blade_PE | rear | Conductive copper-alloy rear-blade candidate; interface and joint qualification pending | 410.5 | 1 | Engineering development; no production or energizing release
Contact_L | Dual-leaf L receptacle spring candidate | contact_carrier | Spring-temper copper-alloy candidate; 0.4 mm leaves, temper/plating unqualified | 345.01093 | 1 | Engineering development; no production or energizing release
Contact_N | Dual-leaf N receptacle spring candidate | contact_carrier | Spring-temper copper-alloy candidate; 0.4 mm leaves, temper/plating unqualified | 145.0 | 1 | Engineering development; no production or energizing release
Contact_PE | Dual-leaf E receptacle spring candidate | contact_carrier | Spring-temper copper-alloy candidate; 0.4 mm leaves, temper/plating unqualified | 173.0 | 1 | Engineering development; no production or energizing release
Screw_0 | Screw_0 | contact_carrier | Spring/fastener metal candidate | 234.707281 | 1 | Engineering development; no production or energizing release
Screw_1 | Screw_1 | contact_carrier | Spring/fastener metal candidate | 234.707281 | 1 | Engineering development; no production or energizing release
Screw_2 | Screw_2 | contact_carrier | Spring/fastener metal candidate | 234.707281 | 1 | Engineering development; no production or energizing release
Screw_3 | Screw_3 | contact_carrier | Spring/fastener metal candidate | 234.707281 | 1 | Engineering development; no production or energizing release
RFServiceSlackEnvelope | Non-physical44mm coax service-slack reservation | rf | NON-PHYSICAL ROUTING RESERVATION; exclude from mass/procurement and default renders | 326.631388 | 1 | Engineering development; no production or energizing release
RFAntenna | Taoglas FXP73.07.0100A antenna envelope | rf | Flexible RF antenna laminate and adhesive envelope | 32.9 | 1 | Engineering development; no production or energizing release
RFCoax | 1.13 mm coax nominal routed segment | rf | Insulated coax routed segment; remaining44mm allocated in retained service-loop reservation | 56.026536 | 1 | Engineering development; no production or energizing release
RFConnectorEnvelope | Mated RF connector clearance envelope | rf | Provisional mating/strain-relief envelope, not vendor detailed CAD | 21.20575 | 1 | Engineering development; no production or energizing release
HeadConnectorEnvelope | Sensor-header mating-housing clearance envelope | thermal | Provisional mating/strain-relief envelope, not vendor detailed CAD | 253.44 | 1 | Engineering development; no production or energizing release
HeadPigtail_0 | Isolated sensor pigtail 0 | thermal | Insulated low-current copper lead envelope | 47.948162 | 1 | Engineering development; no production or energizing release
HeadPigtail_1 | Isolated sensor pigtail 1 | thermal | Insulated low-current copper lead envelope | 47.948162 | 1 | Engineering development; no production or energizing release
HeadPigtail_2 | Isolated sensor pigtail 2 | thermal | Insulated low-current copper lead envelope | 47.948162 | 1 | Engineering development; no production or energizing release
AuxFuseCradle | Underside 1 A auxiliary-fuse two-saddle cradle | rear | PC-FR insulating resin candidate | 140.6067 | 1 | Engineering development; no production or energizing release
AuxFuseRetainer | Auxiliary-fuse retaining bridge | rear | PC-FR insulating resin candidate | 42.42 | 1 | Engineering development; no production or energizing release
PowerCore_L_RAW | PowerCore_L_RAW | supported_power_links | Cu-ETP candidate; forming/joint qualification pending | 312.092461 | 1 | Engineering development; no production or energizing release
PowerCarrier_L_RAW | PowerCarrier_L_RAW | supported_power_links | PC-FR insulating resin candidate | 1020.939288 | 1 | Engineering development; no production or energizing release
PowerCore_N_RAW | PowerCore_N_RAW | supported_power_links | Cu-ETP candidate; forming/joint qualification pending | 290.085014 | 1 | Engineering development; no production or energizing release
PowerCarrier_N_RAW | PowerCarrier_N_RAW | supported_power_links | PC-FR insulating resin candidate | 871.038134 | 1 | Engineering development; no production or energizing release
PowerCore_L_FUSE_THERMAL | PowerCore_L_FUSE_THERMAL | supported_power_links | Cu-ETP candidate; forming/joint qualification pending | 270.181917 | 1 | Engineering development; no production or energizing release
PowerCarrier_L_FUSE_THERMAL | PowerCarrier_L_FUSE_THERMAL | supported_power_links | PC-FR insulating resin candidate | 811.804367 | 1 | Engineering development; no production or energizing release
PowerCore_L_PROTECTED | PowerCore_L_PROTECTED | supported_power_links | Cu-ETP candidate; forming/joint qualification pending | 335.723384 | 1 | Engineering development; no production or energizing release
PowerCarrier_L_PROTECTED | PowerCarrier_L_PROTECTED | supported_power_links | PC-FR insulating resin candidate | 1043.190487 | 1 | Engineering development; no production or energizing release
PowerCore_L_OUTPUT | PowerCore_L_OUTPUT | supported_power_links | Cu-ETP candidate; forming/joint qualification pending | 287.813518 | 1 | Engineering development; no production or energizing release
PowerCarrier_L_OUTPUT | PowerCarrier_L_OUTPUT | supported_power_links | PC-FR insulating resin candidate | 877.09252 | 1 | Engineering development; no production or energizing release
PowerCore_N_OUTPUT | PowerCore_N_OUTPUT | supported_power_links | Cu-ETP candidate; forming/joint qualification pending | 245.253259 | 1 | Engineering development; no production or energizing release
PowerCarrier_N_OUTPUT | PowerCarrier_N_OUTPUT | supported_power_links | PC-FR insulating resin candidate | 732.387636 | 1 | Engineering development; no production or energizing release
MainFuseHolder | Custom insulating carrier for CQP clips | main_fuse | PC-FR insulating resin candidate | 1310.019922 | 1 | Engineering development; no production or energizing release
MainFuseCeramic | SHF main-fuse cartridge ceramic envelope | main_fuse | Ceramic cartridge envelope | 604.882053 | 1 | Engineering development; no production or energizing release
MainFuseCap1 | SHF8020.5080 cartridge end-cap envelope | main_fuse | Conductive metal candidate | 201.099531 | 1 | Engineering development; no production or energizing release
MainFuseCap2 | SHF8020.5080 cartridge end-cap envelope | main_fuse | Conductive metal candidate | 201.099531 | 1 | Engineering development; no production or energizing release
MainFuseClip1 | SCHURTER CQP8040.0003 clip envelope | main_fuse | Silver-plated conductive spring clip | 139.694451 | 1 | Engineering development; no production or energizing release
MainFuseClip2 | SCHURTER CQP8040.0003 clip envelope | main_fuse | Silver-plated conductive spring clip | 139.694451 | 1 | Engineering development; no production or energizing release
MainFuseCollector1 | MainFuseCollector1 | main_fuse | Cu-ETP candidate; forming/joint qualification pending | 52.48 | 1 | Engineering development; no production or energizing release
MainFuseCollector2 | MainFuseCollector2 | main_fuse | Cu-ETP candidate; forming/joint qualification pending | 52.48 | 1 | Engineering development; no production or energizing release
MainFuseRetainer | Main-fuse retaining frame | main_fuse | PC-FR insulating resin candidate | 178.426117 | 1 | Engineering development; no production or energizing release
FuseRetainerScrew_0 | FuseRetainerScrew_0 | main_fuse | Spring/fastener metal candidate | 26.515042 | 1 | Engineering development; no production or energizing release
FuseRetainerScrew_1 | FuseRetainerScrew_1 | main_fuse | Spring/fastener metal candidate | 26.515042 | 1 | Engineering development; no production or energizing release
FuseRetainerScrew_2 | FuseRetainerScrew_2 | main_fuse | Spring/fastener metal candidate | 26.515042 | 1 | Engineering development; no production or energizing release
FuseRetainerScrew_3 | FuseRetainerScrew_3 | main_fuse | Spring/fastener metal candidate | 26.515042 | 1 | Engineering development; no production or energizing release
ThermalBody | TF1 independent one-shot thermal cutoff envelope | thermal | PC-FR insulating resin candidate | 184.725648 | 1 | Engineering development; no production or energizing release
ThermalLead1 | ThermalLead1 | thermal | Conductive metal candidate | 3.769911 | 1 | Engineering development; no production or energizing release
ThermalLead2 | ThermalLead2 | thermal | Conductive metal candidate | 3.769911 | 1 | Engineering development; no production or energizing release
ThermalSleeve | TF1 0.5 mm radial dielectric thermal sleeve | thermal | PC-FR insulating resin candidate | 148.440253 | 1 | Engineering development; no production or energizing release
ThermalRetainer | TF1 insulated retaining saddle | thermal | PC-FR insulating resin candidate | 186.096513 | 1 | Engineering development; no production or energizing release
ThermalRetainerScrew_0 | ThermalRetainerScrew_0 | thermal | Spring/fastener metal candidate | 12.377875 | 1 | Engineering development; no production or energizing release
ThermalRetainerScrew_1 | ThermalRetainerScrew_1 | thermal | Spring/fastener metal candidate | 12.377875 | 1 | Engineering development; no production or energizing release

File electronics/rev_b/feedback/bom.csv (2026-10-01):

Reference | Value | MPN candidate | Footprint | Max height mm | Source | Status
R1 | 33k 1% 1W | PR01000103302FA100 | Feedback:PR01_P10.16 | 4.5 | https://www.vishay.com/docs/28729/pr010203.pdf | DEVELOPMENT / VERIFY ASSEMBLY
R2 | 33k 1% 1W | PR01000103302FA100 | Feedback:PR01_P10.16 | 4.5 | https://www.vishay.com/docs/28729/pr010203.pdf | DEVELOPMENT / VERIFY ASSEMBLY
R3 | 33k 1% 1W | PR01000103302FA100 | Feedback:PR01_P10.16 | 4.5 | https://www.vishay.com/docs/28729/pr010203.pdf | DEVELOPMENT / VERIFY ASSEMBLY
R4 | 33k 1% 1W | PR01000103302FA100 | Feedback:PR01_P10.16 | 4.5 | https://www.vishay.com/docs/28729/pr010203.pdf | DEVELOPMENT / VERIFY ASSEMBLY
U1 | ACPL-K376-560E | ACPL-K376-560E | Feedback:SSO8_ACPL_K376 | 3.307 | https://docs.broadcom.com/doc/AV02-2153EN | DEVELOPMENT / VERIFY ASSEMBLY
R5 | 1.8k 1% | RC0603FR-071K8L | Resistor_SMD:R_0603_1608Metric | 0.55 | https://www.yageo.com/en/ProductSearch | DEVELOPMENT / VERIFY ASSEMBLY
C1 | 100nF 16V X7R | GRM188R71C104KA01D | Capacitor_SMD:C_0603_1608Metric | 0.9 | https://www.murata.com/en-us/products/productdetail?partno=GRM188R71C104KA01D | DEVELOPMENT / VERIFY ASSEMBLY
J1 | POST-SWITCH L | Internal harness solder land; wire/strain relief HOLD | Feedback:Wire_Pad_1.2mm | 4 |  | DEVELOPMENT / VERIFY ASSEMBLY
J2 | POST-SWITCH N | Internal harness solder land; wire/strain relief HOLD | Feedback:Wire_Pad_1.2mm | 4 |  | DEVELOPMENT / VERIFY ASSEMBLY
J3 | 3V3 / GND / OUT_N | TSW-103-07-G-S | Connector_PinHeader_2.54mm:PinHeader_1x03_P2.54mm_Vertical | 8.38 | https://www.samtec.com/products/tsw | DEVELOPMENT / VERIFY ASSEMBLY

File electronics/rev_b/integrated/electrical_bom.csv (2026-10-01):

Board | Reference | Source module | Original reference | Value | MPN candidate | Footprint | Height mm | Source URL | Assembly accessory MPN | Accessory quantity
integrated | PS101 | controller | PS1 | IRM-10-5 | IRM-10-5 | Integrated:IRM10_Controller_Candidate | 21.5 | https://www.meanwell.com/Upload/PDF/IRM-10/IRM-10-SPEC.PDF
integrated | K101 | controller | K1 | RT314005 / 5V | RT314005 / 1-1649328-0 | Relay_THT:Relay_SPDT_Schrack-RT1-16A-FormC_RM5mm | 15.7 | https://www.te.com/en/product-1-1649328-0.html
integrated | U101 | controller | U1 | ESP32-C3-WROOM-02U-N4 | ESP32-C3-WROOM-02U-N4 | RF_Module:ESP32-C3-WROOM-02U | 3.35 | https://www.espressif.com/sites/default/files/documentation/esp32-c3-wroom-02_datasheet_en.pdf
integrated | U102 | controller | U2 | AP63203WU-7 | AP63203WU-7 | Package_TO_SOT_SMD:TSOT-23-6 | 1 | https://www.diodes.com/datasheet/download/AP63200-AP63201-AP63203-AP63205.pdf
integrated | L101 | controller | L1 | 3.9uH | SRN4018-3R9M | Inductor_SMD:L_Bourns-SRN4018 | 1.8 | https://www.bourns.com/docs/product-datasheets/srn4018.pdf
integrated | C101 | controller | C1 | 10uF 16V | GRM21-series candidate | Capacitor_SMD:C_0805_2012Metric | 1.25 | https://www.murata.com/en-us/products/capacitor/ceramiccapacitor
integrated | C102 | controller | C2 | 100nF 16V | GRM21-series candidate | Capacitor_SMD:C_0805_2012Metric | 1.25 | https://www.murata.com/en-us/products/capacitor/ceramiccapacitor
integrated | C103 | controller | C3 | 22uF 10V | GRM21-series candidate | Capacitor_SMD:C_0805_2012Metric | 1.25 | https://www.murata.com/en-us/products/capacitor/ceramiccapacitor
integrated | C104 | controller | C4 | 22uF 10V | GRM21-series candidate | Capacitor_SMD:C_0805_2012Metric | 1.25 | https://www.murata.com/en-us/products/capacitor/ceramiccapacitor
integrated | C105 | controller | C5 | 100nF 10V | GRM21-series candidate | Capacitor_SMD:C_0805_2012Metric | 1.25 | https://www.murata.com/en-us/products/capacitor/ceramiccapacitor
integrated | Q101 | controller | Q1 | AO3400A | AO3400A | Package_TO_SOT_SMD:SOT-23 | 1.1 | https://www.aosmd.com/res/data_sheets/AO3400A.pdf
integrated | D101 | controller | D1 | SS14 | SS14 | Diode_SMD:D_SMA | 2.4 | https://www.vishay.com/docs/88746/ss12.pdf
integrated | R101 | controller | R1 | 100R | RC0603FR-07100RL | Resistor_SMD:R_0603_1608Metric | 0.5 | https://www.yageo.com/en/ProductSearch
integrated | R102 | controller | R2 | 100k | RC0603FR-07100KL | Resistor_SMD:R_0603_1608Metric | 0.5 | https://www.yageo.com/en/ProductSearch
integrated | R103 | controller | R3 | 10k | RC0603FR-0710KL | Resistor_SMD:R_0603_1608Metric | 0.5 | https://www.yageo.com/en/ProductSearch
integrated | C106 | controller | C6 | 1uF 10V | GRM21-series candidate | Capacitor_SMD:C_0805_2012Metric | 1.25 | https://www.murata.com/en-us/products/capacitor/ceramiccapacitor
integrated | R104 | controller | R4 | 10k | RC0603FR-0710KL | Resistor_SMD:R_0603_1608Metric | 0.5 | https://www.yageo.com/en/ProductSearch
integrated | R105 | controller | R5 | 10k | RC0603FR-0710KL | Resistor_SMD:R_0603_1608Metric | 0.5 | https://www.yageo.com/en/ProductSearch
integrated | R106 | controller | R6 | 10k | RC0603FR-0710KL | Resistor_SMD:R_0603_1608Metric | 0.5 | https://www.yageo.com/en/ProductSearch
integrated | U103 | controller | U3 | TMP102AIDRLR | TMP102AIDRLR | Package_TO_SOT_SMD:SOT-563 | 0.6 | https://www.ti.com/lit/ds/symlink/tmp102.pdf
integrated | R107 | controller | R7 | 4.7k | RC0603FR-074K7L | Resistor_SMD:R_0603_1608Metric | 0.5 | https://www.yageo.com/en/ProductSearch
integrated | R108 | controller | R8 | 4.7k | RC0603FR-074K7L | Resistor_SMD:R_0603_1608Metric | 0.5 | https://www.yageo.com/en/ProductSearch
integrated | C107 | controller | C7 | 100nF 10V | GRM21-series candidate | Capacitor_SMD:C_0805_2012Metric | 1.25 | https://www.murata.com/en-us/products/capacitor/ceramiccapacitor
integrated | J102 | controller | J2 | SWITCHED OUT - HOLD | 1868076 | Integrated:MKDS5_2_7p62 | 21.5 | https://www.phoenixcontact.com/us/products/1868076/pdf
integrated | J104 | controller | J4 | DEBUG - MAINS DISCONNECTED | Samtec TSW-1xx-07 candidate | Connector_PinHeader_2.54mm:PinHeader_1x05_P2.54mm_Vertical | 8 | https://www.samtec.com/products/tsw
integrated | SW101 | controller | SW1 | LOCAL BUTTON | B3F-1000 candidate | Button_Switch_THT:SW_PUSH_6mm | 4.3 | https://components.omron.com/us-en/products/switches/B3F
integrated | LED101 | controller | LED1 | STATUS LED GREEN | WP710A10GD candidate | LED_THT:LED_D3.0mm | 5.3 | https://www.kingbrightusa.com/
integrated | R110 | controller | R10 | 10k | RC0603FR-0710KL | Resistor_SMD:R_0603_1608Metric | 0.5 | https://www.yageo.com/en/ProductSearch
integrated | R111 | controller | R11 | 1k | RC0603FR-071KL | Resistor_SMD:R_0603_1608Metric | 0.5 | https://www.yageo.com/en/ProductSearch
integrated | U201 | meter | U1 | ATM90E26-YU | ATM90E26-YU | Package_SO:SSOP-28_5.3x10.2mm_P0.65mm | 2.0 | https://ww1.microchip.com/downloads/aemDocuments/documents/OTH/ProductDocuments/DataSheets/Atmel-46002-SE-M90E26-Datasheet.pdf
integrated | U202 | meter | U2 | ISO6741DWR | ISO6741DWR | RevB:ISO6741_DW_8p1 | 2.65 | https://www.ti.com/lit/ds/symlink/iso6741.pdf
integrated | PS201 | meter | PS1 | R05CT05S-R / 3.3V | R05CT05S-R | RevB:R05CT05S_8p1 | 2.65 | https://recom-power.com/pdf/Econoline/RxxCTxx.pdf
integrated | RS201 | meter | RS1 | 1mR / 1% / 8W | CSS4J-4026R-1L00FE | RevB:CSS4J_4026 | 2.92 | https://www.bourns.com/docs/product-datasheets/css4j-4026.pdf
integrated | J201 | meter | J1 | PROTECTED LINE + NEUTRAL INPUT | 1868076 | Integrated:MKDS5_2_7p62 | 21.5 | https://www.phoenixcontact.com/us/products/1868076/pdf
integrated | R201 | meter | R1 | 100R | TNPW0603100RBEEA | Resistor_SMD:R_0603_1608Metric | 0.55 | https://www.vishay.com/docs/28758/tnpw_e3.pdf
integrated | R202 | meter | R2 | 100R | TNPW0603100RBEEA | Resistor_SMD:R_0603_1608Metric | 0.55 | https://www.vishay.com/docs/28758/tnpw_e3.pdf
integrated | C201 | meter | C1 | 330nF 16V | GRM21-series 330nF 16V candidate | Capacitor_SMD:C_0805_2012Metric | 1.25 | https://www.murata.com/en-us/products/capacitor/ceramiccapacitor
integrated | C202 | meter | C2 | 330nF 16V | GRM21-series 330nF 16V candidate | Capacitor_SMD:C_0805_2012Metric | 1.25 | https://www.murata.com/en-us/products/capacitor/ceramiccapacitor
integrated | RV201 | meter | RV1 | 249k | TNPW1206249KBEEA | Resistor_SMD:R_1206_3216Metric | 0.65 | https://www.vishay.com/docs/28758/tnpw_e3.pdf
integrated | RV202 | meter | RV2 | 249k | TNPW1206249KBEEA | Resistor_SMD:R_1206_3216Metric | 0.65 | https://www.vishay.com/docs/28758/tnpw_e3.pdf
integrated | RV203 | meter | RV3 | 249k | TNPW1206249KBEEA | Resistor_SMD:R_1206_3216Metric | 0.65 | https://www.vishay.com/docs/28758/tnpw_e3.pdf
integrated | RV204 | meter | RV4 | 249k | TNPW1206249KBEEA | Resistor_SMD:R_1206_3216Metric | 0.65 | https://www.vishay.com/docs/28758/tnpw_e3.pdf
integrated | RV205 | meter | RV5 | 1k | TNPW08051K00BEEA | Resistor_SMD:R_0805_2012Metric | 0.65 | https://www.vishay.com/docs/28758/tnpw_e3.pdf
integrated | RV206 | meter | RV6 | 1k | TNPW08051K00BEEA | Resistor_SMD:R_0805_2012Metric | 0.65 | https://www.vishay.com/docs/28758/tnpw_e3.pdf
integrated | RV207 | meter | RV7 | 1k | TNPW08051K00BEEA | Resistor_SMD:R_0805_2012Metric | 0.65 | https://www.vishay.com/docs/28758/tnpw_e3.pdf
integrated | CV201 | meter | CV1 | 33nF 16V | GRM21-series 33nF 16V candidate | Capacitor_SMD:C_0805_2012Metric | 1.25 | https://www.murata.com/en-us/products/capacitor/ceramiccapacitor
integrated | CV202 | meter | CV2 | 33nF 16V | GRM21-series 33nF 16V candidate | Capacitor_SMD:C_0805_2012Metric | 1.25 | https://www.murata.com/en-us/products/capacitor/ceramiccapacitor
integrated | R203 | meter | R3 | 0R | RC0805JR-070RL | Resistor_SMD:R_0805_2012Metric | 0.65 | https://www.vishay.com/docs/28758/tnpw_e3.pdf
integrated | C203 | meter | C3 | 100nF 16V | GRM21-series 100nF 16V candidate | Capacitor_SMD:C_0805_2012Metric | 1.25 | https://www.murata.com/en-us/products/capacitor/ceramiccapacitor
integrated | C204 | meter | C4 | 100nF 16V | GRM21-series 100nF 16V candidate | Capacitor_SMD:C_0805_2012Metric | 1.25 | https://www.murata.com/en-us/products/capacitor/ceramiccapacitor
integrated | C205 | meter | C5 | 10uF 10V | GRM21-series 10uF 10V candidate | Capacitor_SMD:C_0805_2012Metric | 1.25 | https://www.murata.com/en-us/products/capacitor/ceramiccapacitor
integrated | C206 | meter | C6 | 1uF 16V | GRM21-series 1uF 16V candidate | Capacitor_SMD:C_0805_2012Metric | 1.25 | https://www.murata.com/en-us/products/capacitor/ceramiccapacitor
integrated | C207 | meter | C7 | 1nF C0G | GRM21-series 1nF C0G candidate | Capacitor_SMD:C_0805_2012Metric | 1.25 | https://www.murata.com/en-us/products/capacitor/ceramiccapacitor
integrated | R204 | meter | R4 | 10k | TNPW080510K0BEEA | Resistor_SMD:R_0805_2012Metric | 0.65 | https://www.vishay.com/docs/28758/tnpw_e3.pdf
integrated | C208 | meter | C8 | 100nF 16V | GRM21-series 100nF 16V candidate | Capacitor_SMD:C_0805_2012Metric | 1.25 | https://www.murata.com/en-us/products/capacitor/ceramiccapacitor
integrated | Y201 | meter | Y1 | ASV-8.192MHZ-LC-S-T / candidate | ASV-8.192MHZ-LC-S-T | Oscillator:Oscillator_SMD_Abracon_ASV-4Pin_7.0x5.1mm | 1.8 | https://abracon.com/Oscillators/ASV.pdf
integrated | CX201 | meter | CX1 | 100nF 16V X7R | GRM188R71C104KA01D | Capacitor_SMD:C_0805_2012Metric | 0.9 | https://www.murata.com/en-us/products/productdetail?partno=GRM188R71C104KA01D
integrated | CP201 | meter | CP1 | 10uF 16V | GRM21-series 10uF 16V candidate | Capacitor_SMD:C_0805_2012Metric | 1.25 | https://www.murata.com/en-us/products/capacitor/ceramiccapacitor
integrated | CP202 | meter | CP2 | 100nF 16V | GRM21-series 100nF 16V candidate | Capacitor_SMD:C_0805_2012Metric | 1.25 | https://www.murata.com/en-us/products/capacitor/ceramiccapacitor
integrated | CP203 | meter | CP3 | 10uF 10V | GRM21-series 10uF 10V candidate | Capacitor_SMD:C_0805_2012Metric | 1.25 | https://www.murata.com/en-us/products/capacitor/ceramiccapacitor
integrated | CP204 | meter | CP4 | 100nF 16V | GRM21-series 100nF 16V candidate | Capacitor_SMD:C_0805_2012Metric | 1.25 | https://www.murata.com/en-us/products/capacitor/ceramiccapacitor
integrated | CI201 | meter | CI1 | 100nF 16V | GRM21-series 100nF 16V candidate | Capacitor_SMD:C_0805_2012Metric | 1.25 | https://www.murata.com/en-us/products/capacitor/ceramiccapacitor
integrated | CI202 | meter | CI2 | 100nF 16V | GRM21-series 100nF 16V candidate | Capacitor_SMD:C_0805_2012Metric | 1.25 | https://www.murata.com/en-us/products/capacitor/ceramiccapacitor
integrated | R205 | meter | R5 | 10k | TNPW080510K0BEEA | Resistor_SMD:R_0805_2012Metric | 0.65 | https://www.vishay.com/docs/28758/tnpw_e3.pdf
integrated | R206 | meter | R6 | 10k | TNPW080510K0BEEA | Resistor_SMD:R_0805_2012Metric | 0.65 | https://www.vishay.com/docs/28758/tnpw_e3.pdf
integrated | R301 | feedback | R1 | 33k 1% 1W | PR01000103302FA100 | Feedback:PR01_P10.16 | 4.5 | https://www.vishay.com/docs/28729/pr010203.pdf
integrated | R302 | feedback | R2 | 33k 1% 1W | PR01000103302FA100 | Feedback:PR01_P10.16 | 4.5 | https://www.vishay.com/docs/28729/pr010203.pdf
integrated | R303 | feedback | R3 | 33k 1% 1W | PR01000103302FA100 | Feedback:PR01_P10.16 | 4.5 | https://www.vishay.com/docs/28729/pr010203.pdf
integrated | R304 | feedback | R4 | 33k 1% 1W | PR01000103302FA100 | Feedback:PR01_P10.16 | 4.5 | https://www.vishay.com/docs/28729/pr010203.pdf
integrated | U301 | feedback | U1 | ACPL-K376-560E | ACPL-K376-560E | Feedback:SSO8_ACPL_K376 | 3.307 | https://docs.broadcom.com/doc/AV02-2153EN
integrated | R305 | feedback | R5 | 1.8k 1% | RC0603FR-071K8L | Resistor_SMD:R_0603_1608Metric | 0.55 | https://www.yageo.com/en/ProductSearch
integrated | C301 | feedback | C1 | 100nF 16V X7R | GRM188R71C104KA01D | Capacitor_SMD:C_0603_1608Metric | 0.9 | https://www.murata.com/en-us/products/productdetail?partno=GRM188R71C104KA01D
remote_sensor | U401 | thermal | U1 | TMP302BDRLR | TMP302BDRLR | Package_TO_SOT_SMD:SOT-563 | 0.6 | https://www.ti.com/lit/gpn/TMP302
remote_sensor | R401 | thermal | R1 | 10k 1% | RC0603FR-0710KL | Resistor_SMD:R_0603_1608Metric | 0.55 | https://www.yageo.com/en/ProductSearch
remote_sensor | C401 | thermal | C1 | 100nF 16V X7R | GRM188R71C104KA01D | Capacitor_SMD:C_0603_1608Metric | 0.9 | https://www.murata.com/en-us/products/productdetail?partno=GRM188R71C104KA01D
integrated | U402 | thermal | U2 | SN74LVC1G17DBVR | SN74LVC1G17DBVR | Package_TO_SOT_SMD:SOT-23-5 | 1.45 | https://www.ti.com/lit/ds/symlink/sn74lvc1g17.pdf
integrated | R402 | thermal | R2 | 100k 1% | RC0603FR-07100KL | Resistor_SMD:R_0603_1608Metric | 0.55 | https://www.yageo.com/en/ProductSearch
integrated | C402 | thermal | C2 | 100nF 16V X7R | GRM188R71C104KA01D | Capacitor_SMD:C_0603_1608Metric | 0.9 | https://www.murata.com/en-us/products/productdetail?partno=GRM188R71C104KA01D
integrated | U403 | thermal | U3 | TPS3808G30DBVR | TPS3808G30DBVR | Package_TO_SOT_SMD:SOT-23-6 | 1.45 | https://www.ti.com/lit/ds/symlink/tps3808.pdf
integrated | R403 | thermal | R3 | 100k 1% | RC0603FR-07100KL | Resistor_SMD:R_0603_1608Metric | 0.55 | https://www.yageo.com/en/ProductSearch
integrated | R404 | thermal | R4 | 10k 1% | RC0603FR-0710KL | Resistor_SMD:R_0603_1608Metric | 0.55 | https://www.yageo.com/en/ProductSearch
integrated | C403 | thermal | C3 | 100nF 16V X7R | GRM188R71C104KA01D | Capacitor_SMD:C_0603_1608Metric | 0.9 | https://www.murata.com/en-us/products/productdetail?partno=GRM188R71C104KA01D
integrated | U404 | thermal | U4 | SN74LVC1G74DCUR | SN74LVC1G74DCUR | Package_SO:VSSOP-8_2.3x2mm_P0.5mm | 1.1 | https://www.ti.com/lit/ds/symlink/sn74lvc1g74.pdf
integrated | C404 | thermal | C4 | 100nF 16V X7R | GRM188R71C104KA01D | Capacitor_SMD:C_0603_1608Metric | 0.9 | https://www.murata.com/en-us/products/productdetail?partno=GRM188R71C104KA01D
integrated | J403 | thermal | J3 | SENSOR HARNESS | TSW-103-07-G-S | Connector_PinHeader_2.54mm:PinHeader_1x03_P2.54mm_Vertical | 8.38 | https://www.samtec.com/products/tsw-103-07-g-s
remote_sensor | J404 | thermal | J4 | SENSOR PIGTAIL | Soldered insulated pigtail / strain relief HOLD | Thermal:Sensor_Pigtail_3xP2.54 | 2.0
integrated | SW401 | thermal | SW1 | MANUAL REARM | B3F-1000 | Button_Switch_THT:SW_PUSH_6mm | 4.3 | https://components.omron.com/us-en/products/switches/B3F
integrated | R405 | thermal | R5 | 1k 1% | RC0603FR-071KL | Resistor_SMD:R_0603_1608Metric | 0.55 | https://www.yageo.com/en/ProductSearch
integrated | R407 | thermal | R7 | 100k 1% | RC0603FR-07100KL | Resistor_SMD:R_0603_1608Metric | 0.55 | https://www.yageo.com/en/ProductSearch
integrated | C405 | thermal | C5 | 100nF 16V X7R | GRM188R71C104KA01D | Capacitor_SMD:C_0603_1608Metric | 0.9 | https://www.murata.com/en-us/products/productdetail?partno=GRM188R71C104KA01D
integrated | U405 | thermal | U5 | SN74LVC1G17DBVR | SN74LVC1G17DBVR | Package_TO_SOT_SMD:SOT-23-5 | 1.45 | https://www.ti.com/lit/ds/symlink/sn74lvc1g17.pdf
integrated | C406 | thermal | C6 | 100nF 16V X7R | GRM188R71C104KA01D | Capacitor_SMD:C_0603_1608Metric | 0.9 | https://www.murata.com/en-us/products/productdetail?partno=GRM188R71C104KA01D
integrated | Q401 | thermal | Q1 | AO3401A | AO3401A | Package_TO_SOT_SMD:SOT-23 | 1.12 | https://www.aosmd.com/res/data_sheets/AO3401A.pdf
integrated | R409 | thermal | R9 | 47k 1% | RC0603FR-0747KL | Resistor_SMD:R_0603_1608Metric | 0.55 | https://www.yageo.com/en/ProductSearch
integrated | Q402 | thermal | Q2 | MMBT3904 | MMBT3904,215 | Package_TO_SOT_SMD:SOT-23 | 1.1 | https://assets.nexperia.com/documents/data-sheet/MMBT3904.pdf
integrated | Q403 | thermal | Q3 | MMBT3904 | MMBT3904,215 | Package_TO_SOT_SMD:SOT-23 | 1.1 | https://assets.nexperia.com/documents/data-sheet/MMBT3904.pdf
integrated | R410 | thermal | R10 | 10k 1% | RC0603FR-0710KL | Resistor_SMD:R_0603_1608Metric | 0.55 | https://www.yageo.com/en/ProductSearch
integrated | R411 | thermal | R11 | 100k 1% | RC0603FR-07100KL | Resistor_SMD:R_0603_1608Metric | 0.55 | https://www.yageo.com/en/ProductSearch
integrated | R412 | thermal | R12 | 47k 1% | RC0603FR-0747KL | Resistor_SMD:R_0603_1608Metric | 0.55 | https://www.yageo.com/en/ProductSearch
integrated | R413 | thermal | R13 | 100k 1% | RC0603FR-07100KL | Resistor_SMD:R_0603_1608Metric | 0.55 | https://www.yageo.com/en/ProductSearch
integrated | U406 | thermal | U6 | SN74LVC1G17DBVR | SN74LVC1G17DBVR | Package_TO_SOT_SMD:SOT-23-5 | 1.45 | https://www.ti.com/lit/ds/symlink/sn74lvc1g17.pdf
integrated | C407 | thermal | C7 | 100nF 16V X7R | GRM188R71C104KA01D | Capacitor_SMD:C_0603_1608Metric | 0.9 | https://www.murata.com/en-us/products/productdetail?partno=GRM188R71C104KA01D
integrated | TP401 | thermal | TP1 | COIL_ARMED | PCB TEST PAD ONLY | TestPoint:TestPoint_Pad_D1.0mm | 0
integrated | TP402 | thermal | TP2 | THERMAL_READY | PCB TEST PAD ONLY | TestPoint:TestPoint_Pad_D1.0mm | 0
integrated | F501 | integrated |  | 1A T 250VAC AUX FUSE / HOLD | 0215001.MXEP | Integrated:Fuse_215_Axial_P30mm | 7.3 | https://www.littelfuse.com/assetdocs/littelfuse_fuse_215_datasheet.pdf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
off_board_assembly | F601 | assembly | F601 | F_MAIN / 16A FAST 500VAC | 8020.5080 |  |  | https://www.schurter.com/en/datasheet/typ_SHF_6.3x32.pdf | 8040.0003 | 2
off_board_assembly | TF601 | assembly | TF601 | THERMAL LINK / Tf110C / SUFFIX HOLD | MICROTEMP G5 Tf110C; exact suffix HOLD |  |  | https://www.sensience.com/wp-content/uploads/2022/12/Microtemp_Catalog.pdf
off_board_assembly | J601 | assembly | J601 | PLUG BLADES / L N PE / ASSEMBLY HOLD | Custom mechanical plug blade assembly
off_board_assembly | J602 | assembly | J602 | SOCKET CONTACTS / L N PE / ASSEMBLY HOLD | Custom mechanical socket contact assembly

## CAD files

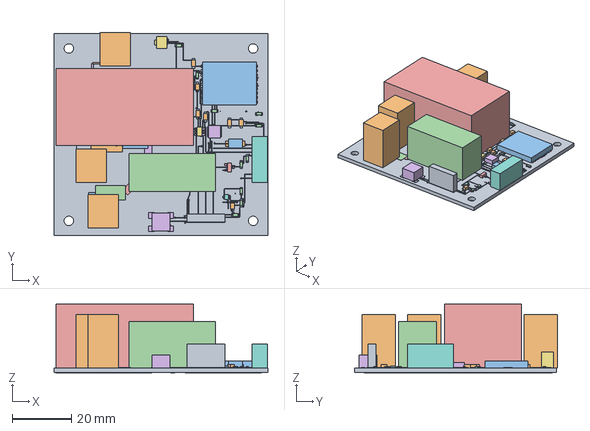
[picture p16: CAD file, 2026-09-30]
electronics/rev_b/controller/exports/pcb_assembly.step
72.0 x 68.5 x 23.2 mm

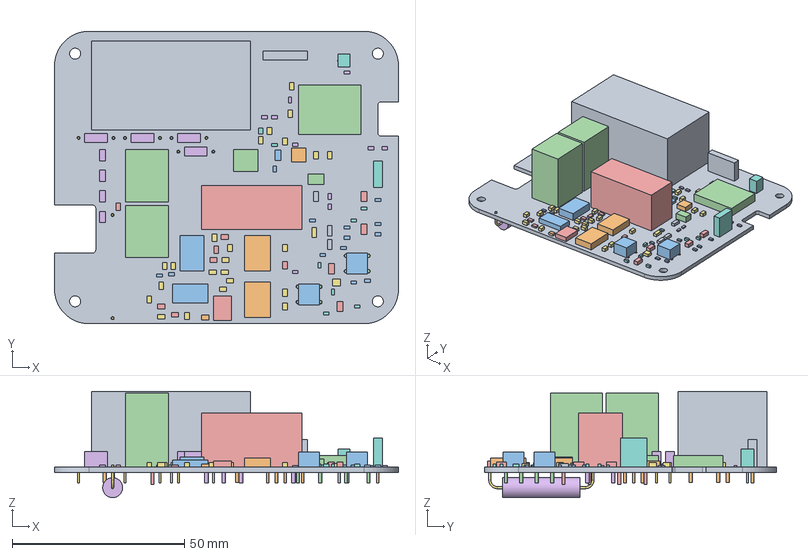
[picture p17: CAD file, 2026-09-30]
electronics/rev_b/integrated/exports/placement_assembly.step
100.0 x 85.0 x 30.9 mm

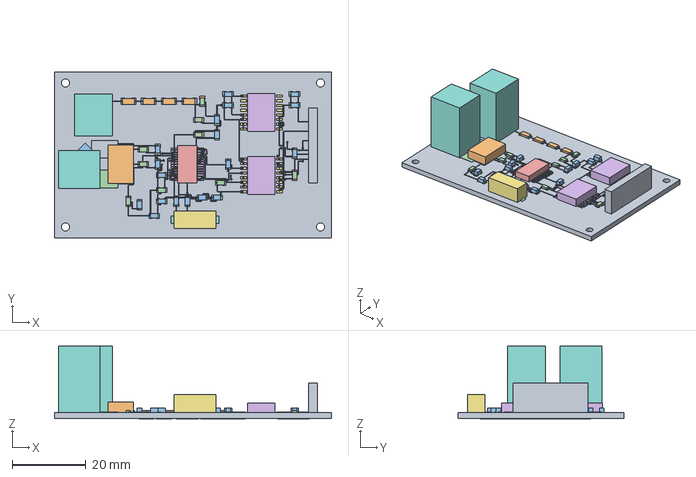
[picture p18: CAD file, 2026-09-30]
electronics/rev_b/meter/exports/meter_assembly.step
75.0 x 45.0 x 19.7 mm

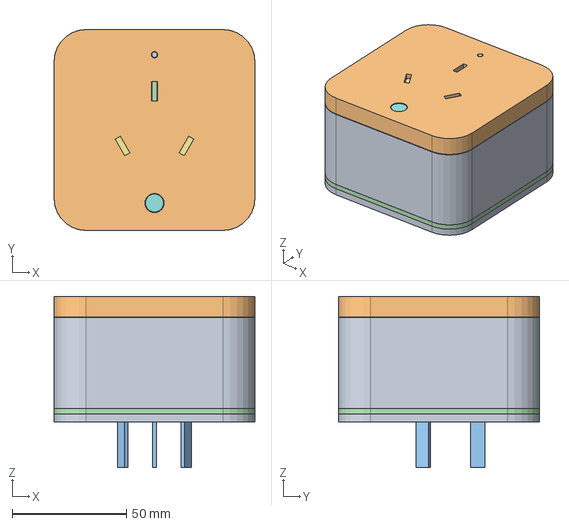
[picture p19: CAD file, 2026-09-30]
mechanical/CARBENTRA-P16-SystemAssembly.step
88.1 x 88.1 x 75.0 mm

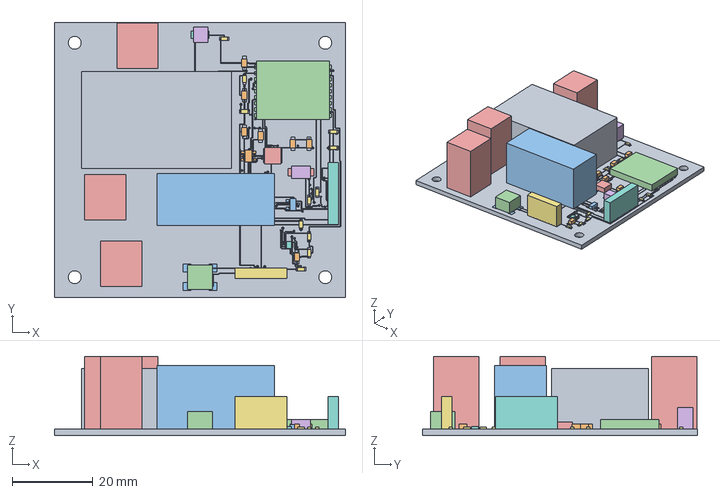
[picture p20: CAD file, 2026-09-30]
electronics/exports/pcb_assembly.step
72.0 x 68.0 x 19.6 mm

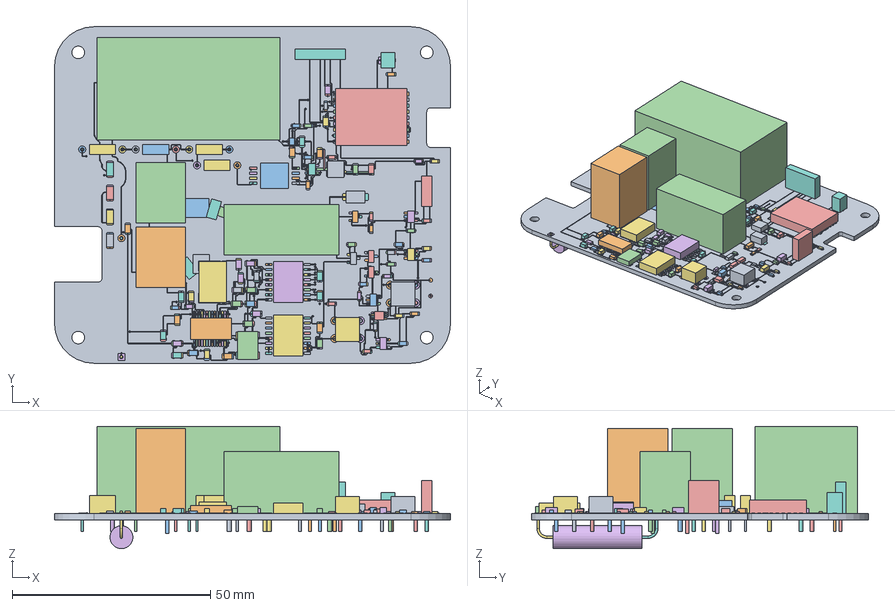
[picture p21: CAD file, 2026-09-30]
electronics/rev_b/integrated/exports/integrated_assembly.FCStd
100.0 x 85.0 x 30.9 mm
MainB_PCB_100x85_R10_4layer
MainB_CX201
MainB_R201
MainB_J102
MainB_J102_Pin1
MainB_J102_Pin2
MainB_R105
MainB_C101
MainB_R103
MainB_C107
MainB_U103
MainB_C203
MainB_R101
MainB_R202
MainB_R405
MainB_J104
MainB_J104_Tail1
MainB_J104_Tail2
MainB_J104_Tail3
MainB_J104_Tail4
MainB_J104_Tail5
MainB_CP203
MainB_RS201
MainB_CV201
MainB_CI202
MainB_R111
MainB_R404
MainB_C205
MainB_U101
MainB_RV206
MainB_R303
MainB_R303_Tail1
MainB_R303_Tail2
MainB_C102
MainB_C405
MainB_PS101
MainB_PS101_Tail1
MainB_PS101_Tail2
MainB_PS101_Tail3
MainB_PS101_Tail4
MainB_SW401
MainB_SW401_Tail1
MainB_SW401_Tail002
MainB_SW401_Tail2
MainB_SW401_Tail003
MainB_U402
MainB_R304
MainB_R304_Tail1
MainB_R304_Tail2
MainB_C206
MainB_R302
MainB_R302_Tail1
MainB_R302_Tail2
MainB_R104
MainB_CV202
MainB_RV201
MainB_Q401
MainB_R407
MainB_C204
MainB_R409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

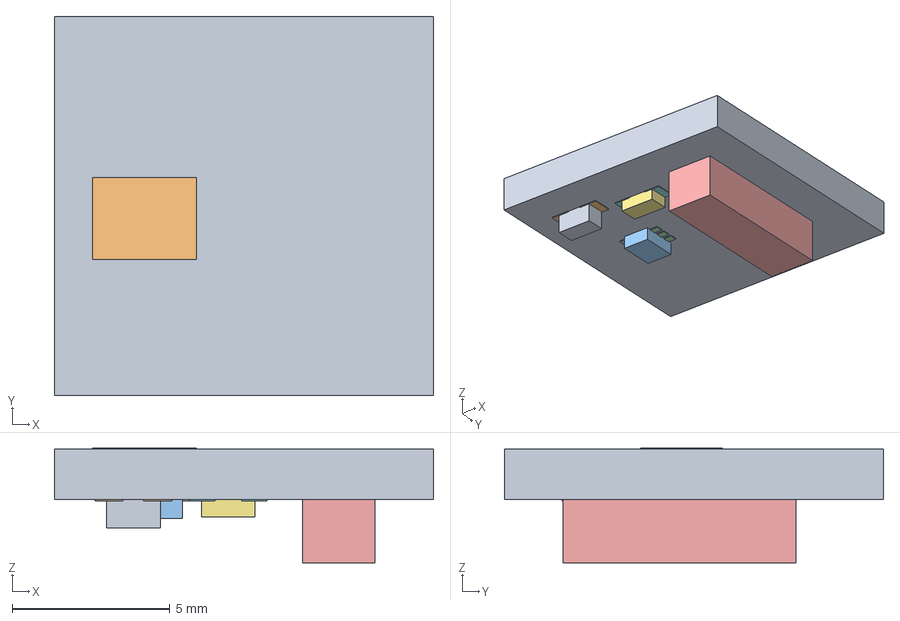
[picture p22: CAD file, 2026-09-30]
electronics/rev_b/integrated/exports/remote_head_assembled.step
12.0 x 12.0 x 3.63 mm

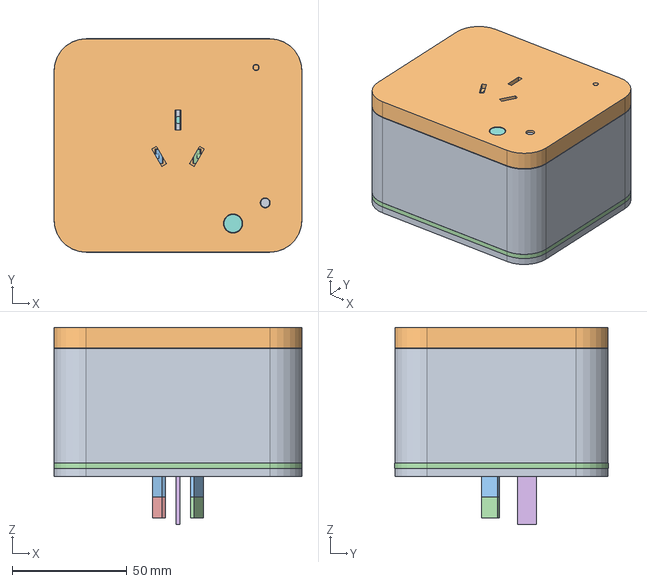
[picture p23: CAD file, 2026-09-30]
mechanical/rev_b/CARBENTRA-P16-EVT-B_system_assembly.step
108.1 x 93.1 x 86.0 mm

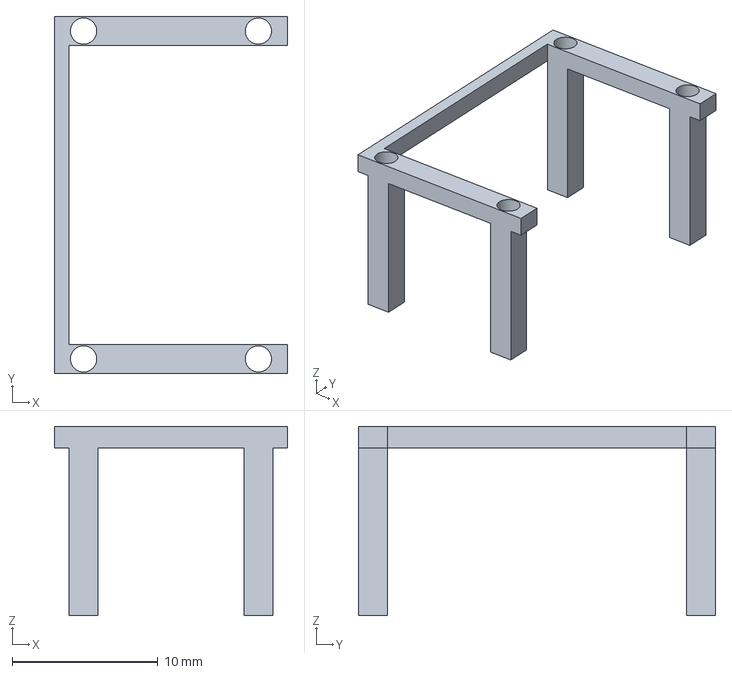
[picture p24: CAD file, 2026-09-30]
mechanical/rev_b/parts/MainFuseRetainer.step
16.0 x 24.5 x 13.0 mm

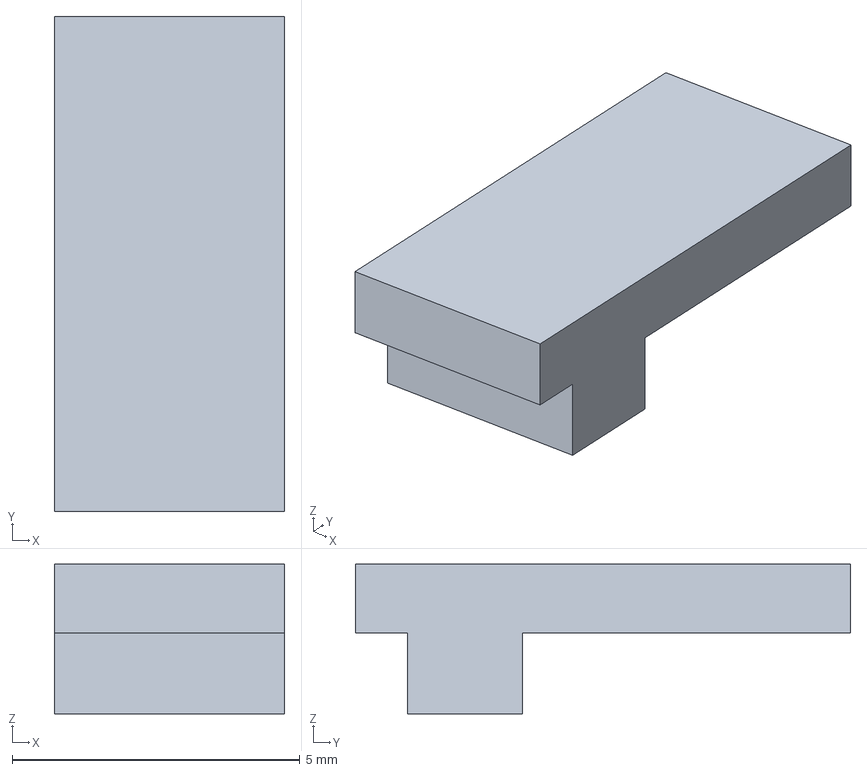
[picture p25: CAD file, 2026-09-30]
mechanical/rev_b/parts/MainFuseCollector2.step
4.00 x 8.60 x 2.60 mm

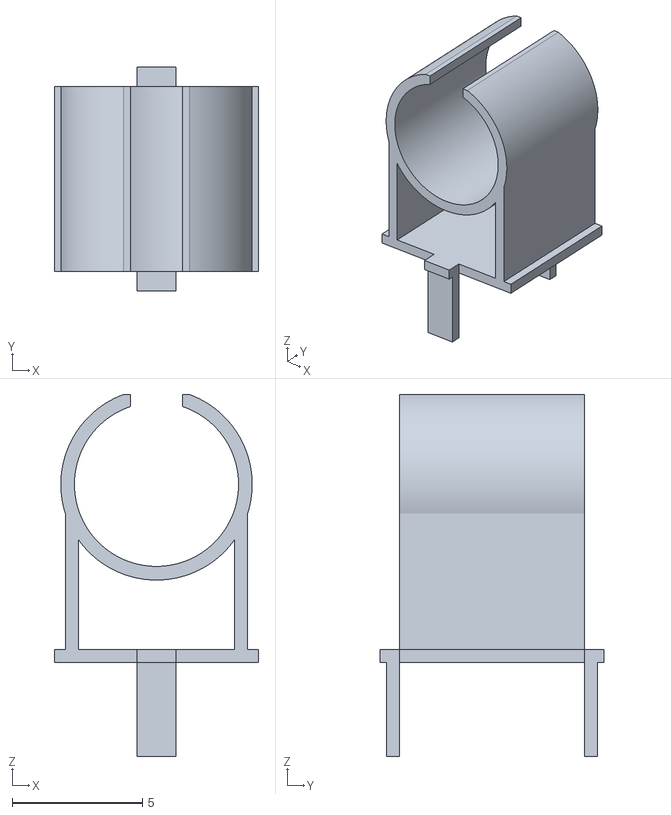
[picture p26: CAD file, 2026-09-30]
mechanical/rev_b/meshes/MainFuseClip1.stl
7.85 x 8.60 x 13.9

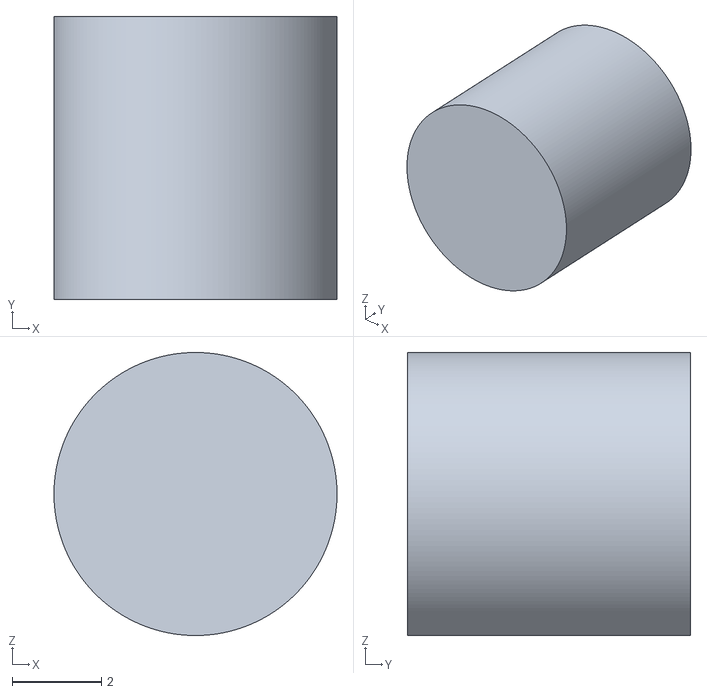
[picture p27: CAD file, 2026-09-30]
mechanical/rev_b/meshes/MainFuseCap1.stl
6.35 x 6.35 x 6.35

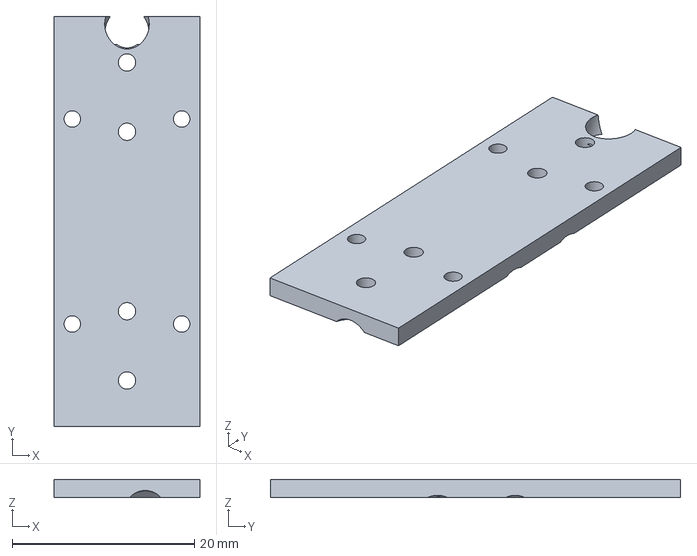
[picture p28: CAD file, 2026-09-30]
mechanical/rev_b/parts/MainFuseHolder.step
16.0 x 45.0 x 2.00 mm

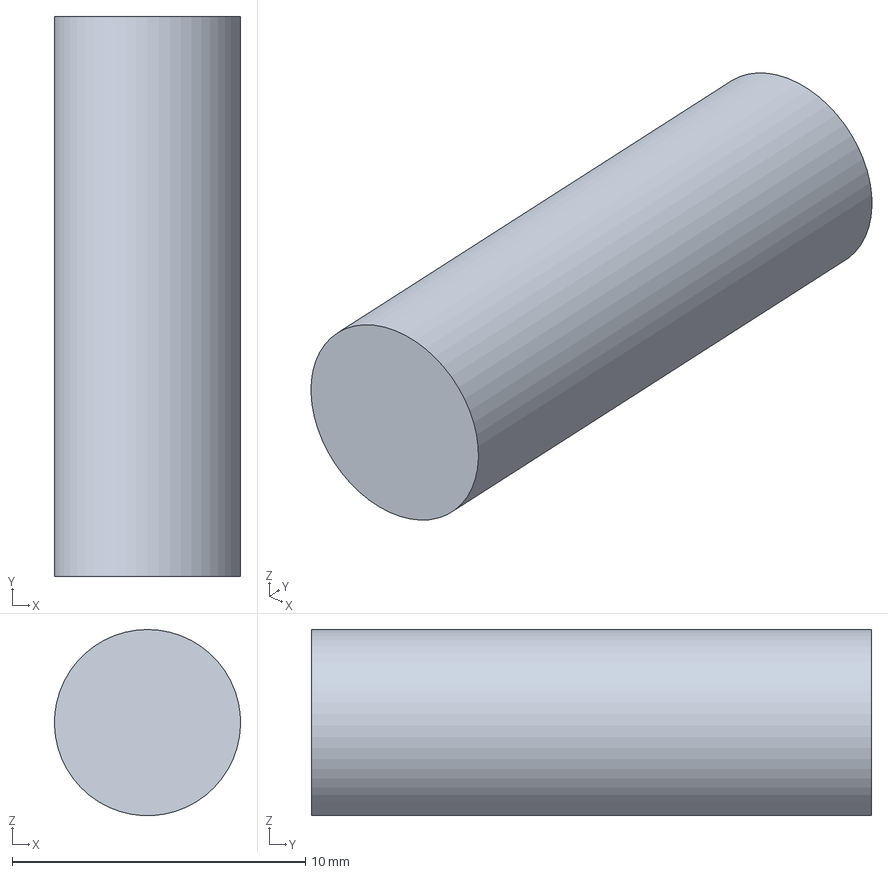
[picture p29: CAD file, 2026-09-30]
mechanical/rev_b/parts/MainFuseCeramic.step
6.35 x 19.1 x 6.34 mm

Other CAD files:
mechanical/rev_b/parts/MainFuseClip1.step
mechanical/rev_b/meshes/MainFuseCollector1.stl
mechanical/rev_b/parts/MainFuseClip2.step
mechanical/rev_b/parts/MainFuseCollector1.step
electronics/exports/pcb_assembly.FCStd
electronics/exports/pcb_native.step
electronics/rev_b/controller/exports/pcb_assembly.FCStd
electronics/rev_b/controller/exports/pcb_assembly.obj
electronics/rev_b/feedback/exports/output_feedback_envelope.FCStd
electronics/rev_b/feedback/exports/output_feedback_envelope.step
electronics/rev_b/integrated/exports/integrated_assembly.obj
electronics/rev_b/integrated/exports/placement_assembly.FCStd
electronics/rev_b/integrated/exports/placement_assembly.obj
electronics/rev_b/integrated/exports/remote_head_assembled.obj
electronics/rev_b/meter/exports/meter_assembly.FCStd
electronics/rev_b/meter/exports/meter_assembly.obj
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

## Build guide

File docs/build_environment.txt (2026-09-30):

Digital build environment
Blender 4.3.2
9.0.2
Python 3.12.14
git version 2.52.0

CAD engine
{
  "engine": "FreeCAD 1.0.0",
  "parts": 20,
  "all_shapes_valid": true,
  "all_single_solid": true,
  "intersections": [
    {
      "a": "PEBus",
      "b": "Blade_PE",
      "volume_mm3": 1.1999999999999997,
      "intentional": true
    },
    {
      "a": "PEBus",
      "b": "Contact_PE",
      "volume_mm3": 0.8999999999999915,
      "intentional": true
    }
  ],
  "note": "Interference audit is geometric only. Electrical safety, creepage, contact force, shutter operation, tolerances, standards and certification are NOT validated."

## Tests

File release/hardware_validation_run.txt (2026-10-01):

CARBENTRA Plug Windows native hardware validation, 2026-10-01

PASS PowerShell scripts/rebuild_windows.ps1: separate source copy rebuilt with native KiCad 10.0.5 and FreeCAD 1.1.4.
PASS four retained/rebuilt native assemblies, 523 object geometries; exact OCC bidirectional Boolean differences and negative controls.
PASS retained/rebuilt PCB layers, footprint/pad/mask/net geometry, 2486 copper objects and planes.
PASS separate rebuilt schematic ERC 0/0, full graph 348 terminals, main PCB 321 numbered pad keys and native DRC 0.
PASS retained PCB native supported-rule/independent shifted-pad negative controls; unsupported rule cannot falsely claim clearance enforcement.
PASS full source/target 3D insulation audit, no input changes, no unintended intersections; minimum nominal screen 8.5166446878 mm, target 8.4 mm.
PASS rear terminal nominal geometric margin.
PASS native Blender 5.2.2 LTS scene GPU render on RTX 5060 Laptop with OptiX; real GLB export of 3223 product meshes.
PASS retained reviewed mechanical/schematic/copper PDFs: original 11-page review remains applicable to byte-identical PDFs; no new PDF visual review claimed.

Authoritative measurements and exact input digests are in hardware_geometry_rebuild.json,
windows-native-scene.json, mechanical/rev_b/*_report.json, electronics/rev_b/integrated/validation/*,
and hardware_recertification.json. No hardware connection, flashing, mains energization,
per-unit calibration, thermal/EMC testing or physical release occurred. Fabrication/energization HOLD.

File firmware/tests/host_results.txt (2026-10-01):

**********************************************************************
** Visual Studio 2022 Developer PowerShell v17.14.38
** Copyright (c) 2025 Microsoft Corporation
**********************************************************************
carbentra_policy.c
test_policy.c
正在生成代码...
PASS local input: commissioning/load/feedback/dwell guards, offline OFF, debounce, manual hold and maintenance
PASS 45 policy cases and 10000 local-trip invariants
carbentra_command_json.c
carbentra_json.c
carbentra_meter_decode.c
cJSON.c
test_protocol.c
正在生成代码...
  正在创建库 D:\Temp\codex\carbentra-fix-20261001\plug\host\test_protocol\test_protocol.lib 和对象 D:\Temp\codex\carbentra-fix-20261001\plug\host\test_protocol\test_protocol.exp
PASS JSON boundaries, meter encodings/checksum/CRC, runtime reset and stuck-link regression
carbentra_feedback.c
test_feedback.c
正在生成代码...
PASS feedback qualification: 50/60Hz, startup, 3 periods, spikes, dropout, stuck LOW and time rollback
carbentra_storage.c
test_storage.c
正在生成代码...
PASS NVS startup: stable namespaces, replay preservation, six injected errors, fresh store and boot overflow; no erase API
carbentra_calibration.c
carbentra_meter_decode.c
carbentra_execution.c
test_calibration_execution.c
正在生成代码...
PASS calibration v3 exact board/revision/CRC and command correlated observed/failed/superseded/deadline terminal states
carbentra_storage.c
carbentra_policy.c
carbentra_feedback.c
carbentra_execution.c
cJSON.c
test_startup.c
D:\code\github\hicancan\carbentra-suite\carbentra-smart-plug\firmware\tests\test_startup.c(54): warning C4305: “=”: 从“double”到“float”截断
正在生成代码...
  正在创建库 D:\Temp\codex\carbentra-fix-20261001\plug\host\test_startup\test_startup.lib 和对象 D:\Temp\codex\carbentra-fix-20261001\plug\host\test_startup\test_startup.exp
PASS app_main mocked startup failure=0: relay off, invalid measurements explicit, journal failure blocks networking; coherent ISR feedback snapshot
PASS app_main mocked startup failure=1: relay off, invalid measurements explicit, journal failure blocks networking; coherent ISR feedback snapshot
PASS app_main mocked startup failure=2: relay off, invalid measurements explicit, journal failure blocks networking; coherent ISR feedback snapshot
PASS app_main mocked startup failure=3: relay off, invalid measurements explicit, journal failure blocks networking; coherent ISR feedback snapshot
PASS app_main mocked startup failure=4: relay off, invalid measurements explicit, journal failure blocks networking; coherent ISR feedback snapshot
PASS app_main mocked startup failure=5: relay off, invalid measurements explicit, journal failure blocks networking; coherent ISR feedback snapshot
PASS app_main mocked startup failure=6: relay off, invalid measurements explicit, journal failure blocks networking; coherent ISR feedback snapshot

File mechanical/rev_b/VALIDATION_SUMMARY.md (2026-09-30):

# CARBENTRA CARBENTRA-P16-EVT-B · Final digital review snapshot

- Envelope:108 ×93 ×65 mm nominal; original design, single16A-class interface
- Mechanical geometry:71 physical parts and1 explicitly non-physical RF slack reservation
- Combined system:234 physical model objects(71 mechanical +144 PCB placement/body/lead +19 remote head); reservation retained only as reference in native CAD
- BRep fit:all valid single solids; zero unintended mechanical, main-board/lead or remote-head intersections. Conductive joints, clip engagement and nominal thread-major/pilot overlaps are listed separately
- Conductive joint geometry:all modeled external interfaces connect; PE forms one continuous solid
- Receptacle spring candidate:0.4 mm leaves,1.7 mm free gap;1.8/1.95 mm prescribed inserted states pass with0.05/0.125 mm displacement per leaf and no rigid insertion obstruction
- Shutter:11 tested states; independent single-pawl attempts are mechanically blocked, both-released travel and full-open passages are clear
- Main-board segregation:8.516645 mm minimum nominal exposed-primary to isolated copper, including the filled plane; passes the project8.4 mm geometry screen
- RF slack:remaining44.134 mm of the100 mm coax allocated in a retained service-loop reservation, assumed minimum bend radius6 mm; default-hidden and excluded from physical STEP/mass/procurement
- Export check:source and delivered cleaned BRep geometry match within1e−10 numeric serialization tolerance; STEP roundtrip has234 valid solids, relative summed-volume difference2.12e-08

## Scope and remaining release gates
This freezes the bounded digital review configuration. It is not a fabrication, energization or certification release. Nominal3D separation is not a qualified clearance/creepage result. The remote thermal pickup intentionally relies on0.5 mm solid insulation, whose material, compression, edges and dielectric behavior require qualification. Contact force/fatigue, plug/receptacle gauges, blade sleeves, fuse/thermal coordination, conductor terminations, screw torque/retention, RF connector/slack strain relief, thermal rise, wall-socket loading and EMC remain explicit gates in docs/.

The PCB bodies and several connector/lead geometries are nominal/max envelopes, not complete vendor internal CAD. The RF reservation allocates routing space; it does not pretend to be a purchased component or an exact cable centerline. Exterior/main-current packaging stayed fixed during the final checks.

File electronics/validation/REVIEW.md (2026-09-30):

# Final validation interpretation

- **ERC:** 0 errors, 0 warnings on the final grouped A3 source
- **Pin/net consistency:** 104 assigned pins across 33 components agree between the real KiCad netlist and physical PCB pads
- **PCB geometry DRC:** 0 violations; no shorts, clearance violations, courtyard overlaps, drill or silk errors
- **Low-voltage routing:** no unconnected items
- **Hazardous routing:** 9 intentional unconnected items on L_AUX_FUSED, L_FUSED, L_SWITCHED, L_NC_UNUSED and N; full list in `drc.rpt`
- **Footprint invariance:** all 37 footprints (33 components + 4 holes) retained their fixed position, rotation, identifier and pad geometry during final routing closure
- **3D:** native KiCad board/copper STEP exported successfully; package-envelope assembly exports are simplified geometry, not vendor-detailed component solids

PWR_FLAG declarations state where the circuit is driven: external auxiliary line/neutral, buck output through the inductor, and the relay's unused NC terminal that becomes live from the common contact. They do not assert voltage safety, fuse operation or hardware correctness. NC is externally unwired but is never treated as a safe floating pad.

The preliminary 8 mm hazardous-to-control clearance rule is checked in the PCB's 2D copper geometry. It does not establish full creepage, primary-to-primary insulation, 3D clearance to conductors/fasteners, material group, altitude, pollution degree, or a product-standard compliance conclusion. Those are release gates.

Native reports are unfiltered. Intermediate routing reports are retained for development provenance; only `erc.rpt`, `drc.rpt`, `net_pin_consistency.json`, `footprint_invariance.json` and `final_summary.json` describe the final canonical release. No physical bench, metrology, relay-load, thermal, EMC, dielectric or production test has run. The board must not be fabricated or energized from this development release.

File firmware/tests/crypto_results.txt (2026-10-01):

**********************************************************************
** Visual Studio 2022 Developer PowerShell v17.14.38
** Copyright (c) 2025 Microsoft Corporation
**********************************************************************
-- Configuring done (0.5s)
-- Generating done (0.0s)
-- Build files have been written to: D:/Temp/codex/carbentra-fix-20261001/plug/crypto/mbedtls
ninja: no work to do.
test_time_signature.c
carbentra_time_signature.c
carbentra_json.c
cJSON.c
正在生成代码...
  正在创建库 D:\Temp\codex\carbentra-fix-20261001\plug\crypto\time_signature\test_time_signature.lib 和对象 D:\Temp\codex\carbentra-fix-20261001\plug\crypto\time_signature\test_time_signature.exp
test_certificate_dates.c
============================= test session starts =============================
platform win32 -- Python 3.12.13, pytest-9.1.1, pluggy-1.6.0 -- D:\code\github\hicancan\carbentra-suite\carbentra-campus-platform\.venv\Scripts\python.exe
cachedir: D:\Temp\codex\carbentra-fix-20261001\plug\crypto\pytest-cache
rootdir: D:\code\github\hicancan\carbentra-suite\carbentra-campus-platform
configfile: pyproject.toml
plugins: anyio-4.15.1
collecting ... collected 3 items

..\carbentra-campus-platform\edge\tests\test_time_bootstrap.py::SignedTimeTests::test_real_firmware_crypto PASSED [ 33%]
..\carbentra-campus-platform\edge\tests\test_time_bootstrap.py::SignedTimeTests::test_signer_rejects_invalid_inputs PASSED [ 66%]
..\carbentra-campus-platform\edge\tests\test_certificate_dates.py::CertificateTests::test_dates_ca_and_hostname PASSED [100%]

- generated xml file: D:\Temp\codex\carbentra-fix-20261001\plug\crypto\crypto-tests.xml -
============================== 3 passed in 0.49s ==============================

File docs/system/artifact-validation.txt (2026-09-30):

Validation date: 2026-09-30
JSON Schema Draft 2020-12: valid
Simulated profiles: 4/4 valid
Invalid capability profiles: 3/3 rejected
Telemetry JSON: parses; explicitly simulated
Architecture SVG: valid XML, rendered with Inkscape to PNG; visually reviewed, no clipped text
Policy reference: 24 unittest cases passed; see policy-test-log.txt
Hardware, cryptography, firmware, metrology, compliance, native AC interface: not implemented or tested

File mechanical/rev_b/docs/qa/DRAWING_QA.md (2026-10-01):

# Drawing presentation QA

Document: CARBENTRA CARBENTRA-P16-EVT-B face-view polarity control
Date: 2026-09-30
Scope: drawing and documentation presentation only; not mechanical, electrical or product validation

- Regenerated the current branded PDF and SVG from the current design parameters on 2026-09-30; rendered the one-page A3 PDF at 1800 px width and inspected the refreshed image
- Confirmed the inherited inset/title layout and line styles remain clear after regeneration
- Confirmed front female L-right/N-left and rear male L-left/N-right, with PE uppermost in both
- Confirmed all three world coordinates, 108/93/65 body dimensions and 21/18 rear projections are present
- Confirmed the source/reference, nominal-envelope and open-release warnings are visible
- Parsed SVG as XML and checked PDF selectable text for brand, polarity, coordinates and release hold
- Verified the local Markdown hyperlinks resolve and the PDF primary-source links are included
- Source SHA-256 values in ../drawing_source_snapshot.json identify the source snapshot when the drawing was generated; this is not evidence of a frozen or validated CAD release

Visual review image: face_view_polarity.png

The supplier catalogue page used for interface review is not redistributed in this documentation set; the primary document is linked in the README and drawing.

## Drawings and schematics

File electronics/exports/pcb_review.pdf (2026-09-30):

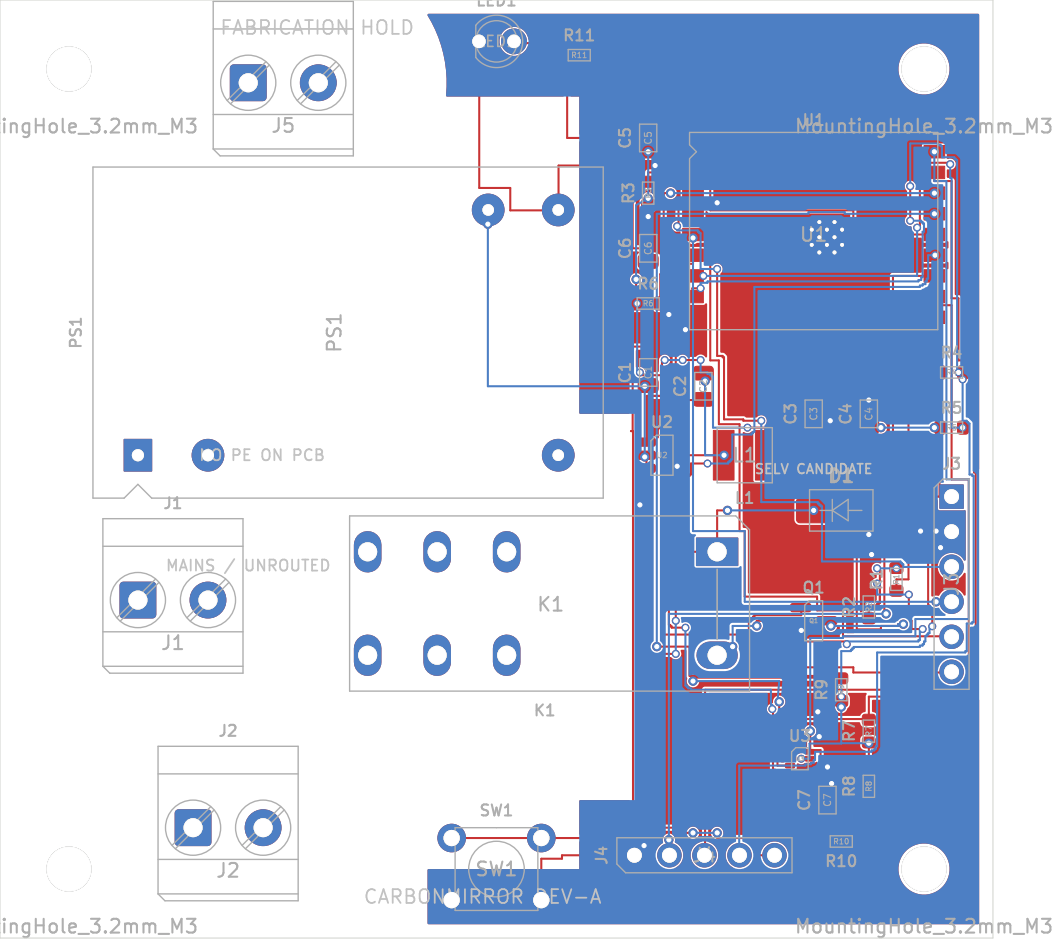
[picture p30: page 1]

NO PE ON PCB

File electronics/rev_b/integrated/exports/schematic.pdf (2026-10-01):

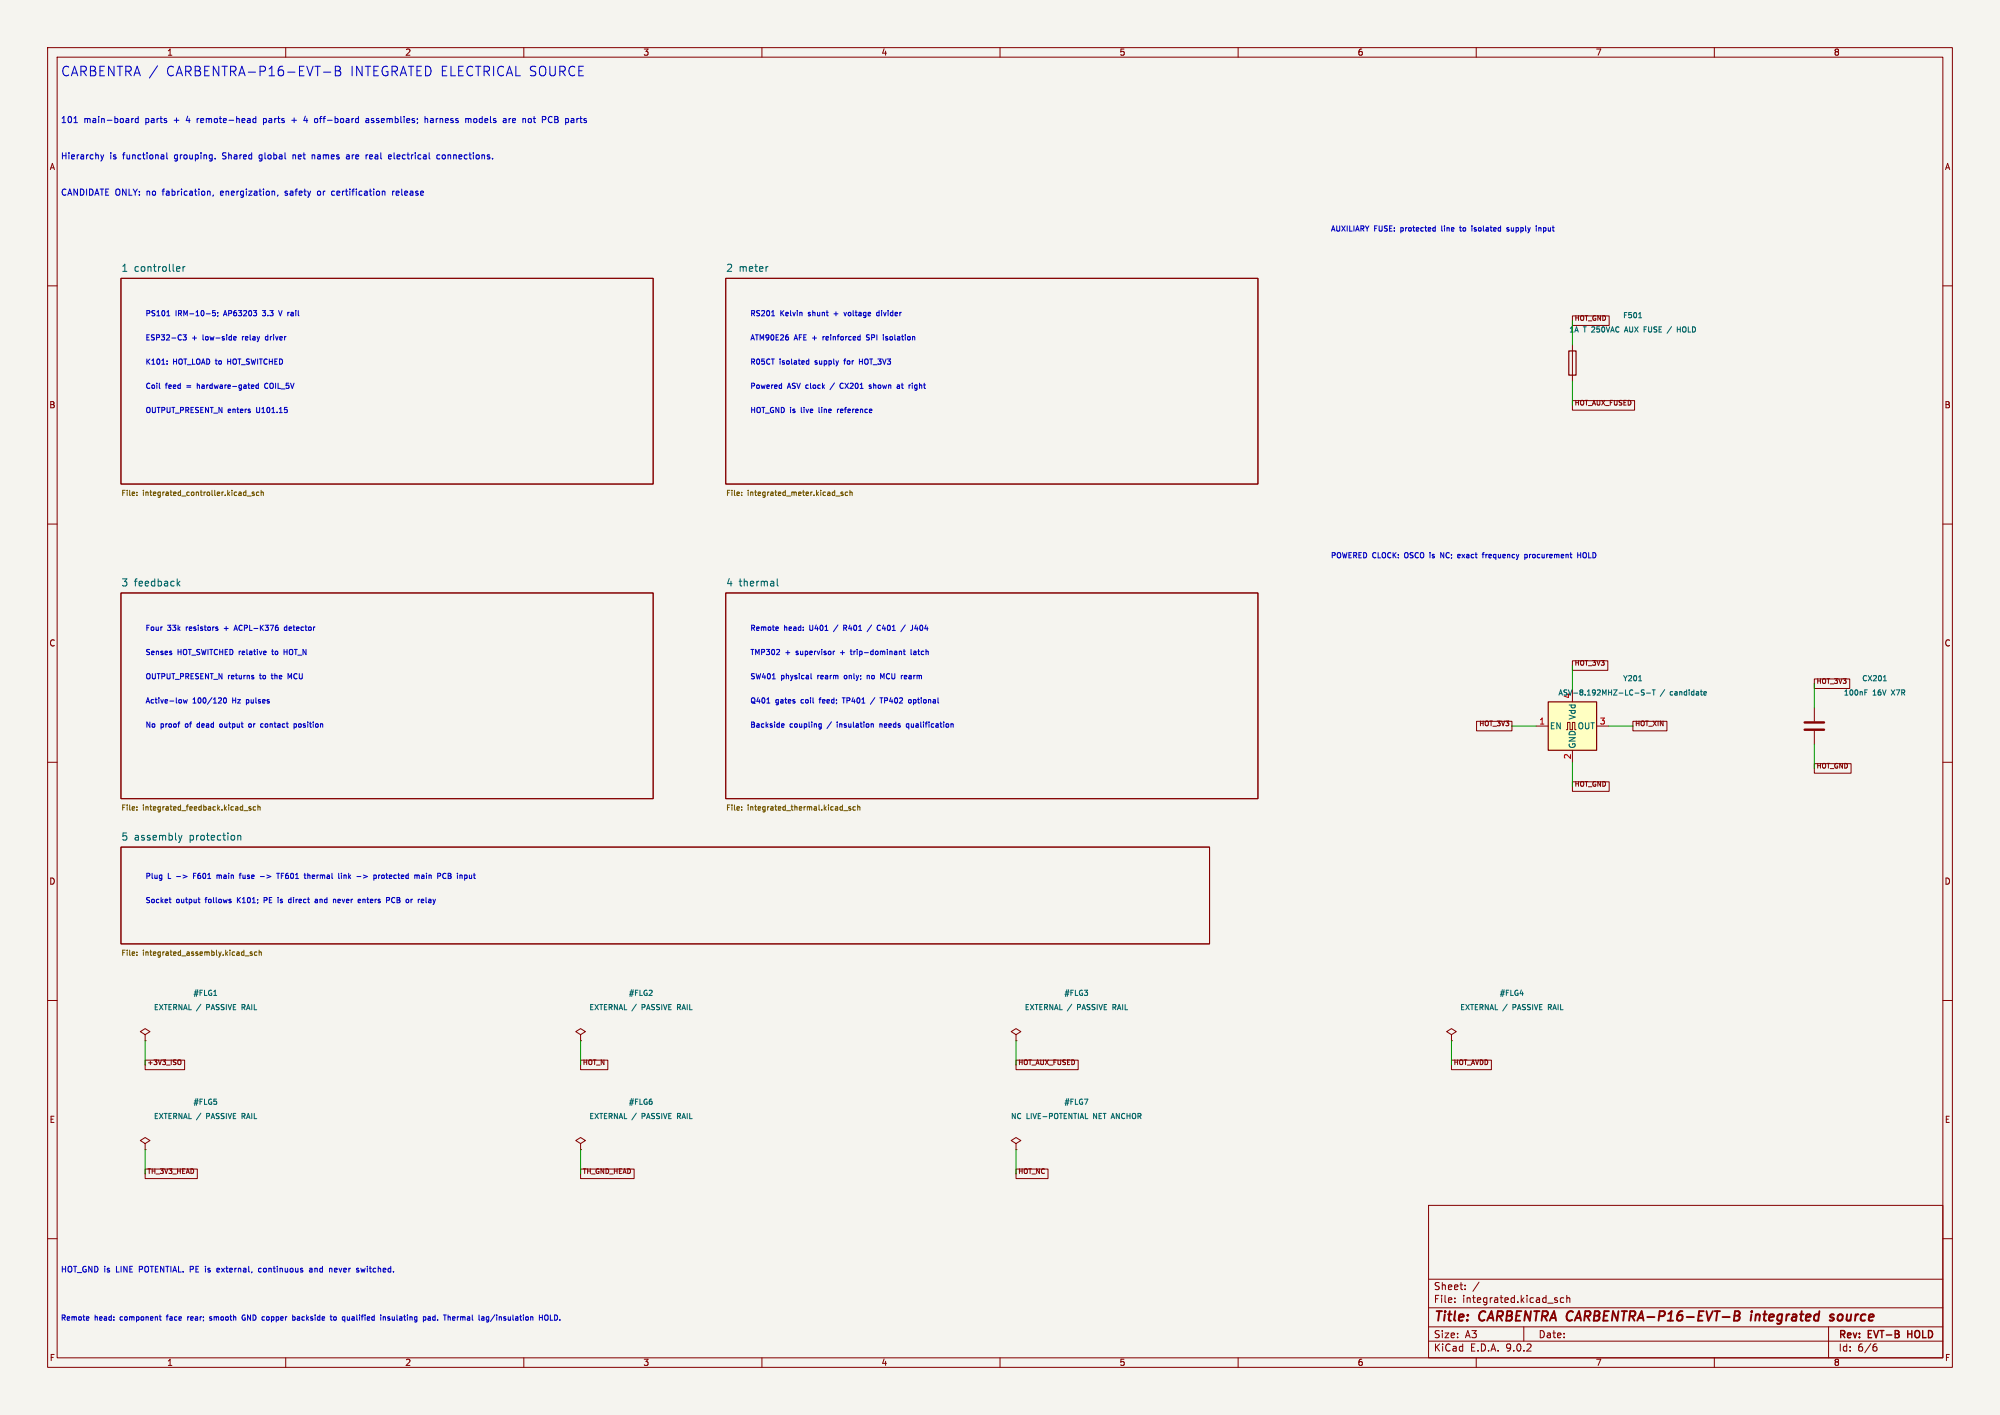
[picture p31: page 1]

2 meter File: integrated_meter.kicad_sch 4 thermal File: integrated_thermal.kicad_sch

2 OUT 3 Y201 ASV-8.192MHZ-LC-S-T / candidate CX201

#FLG7 NC LIVE-POTENTIAL NET ANCHOR

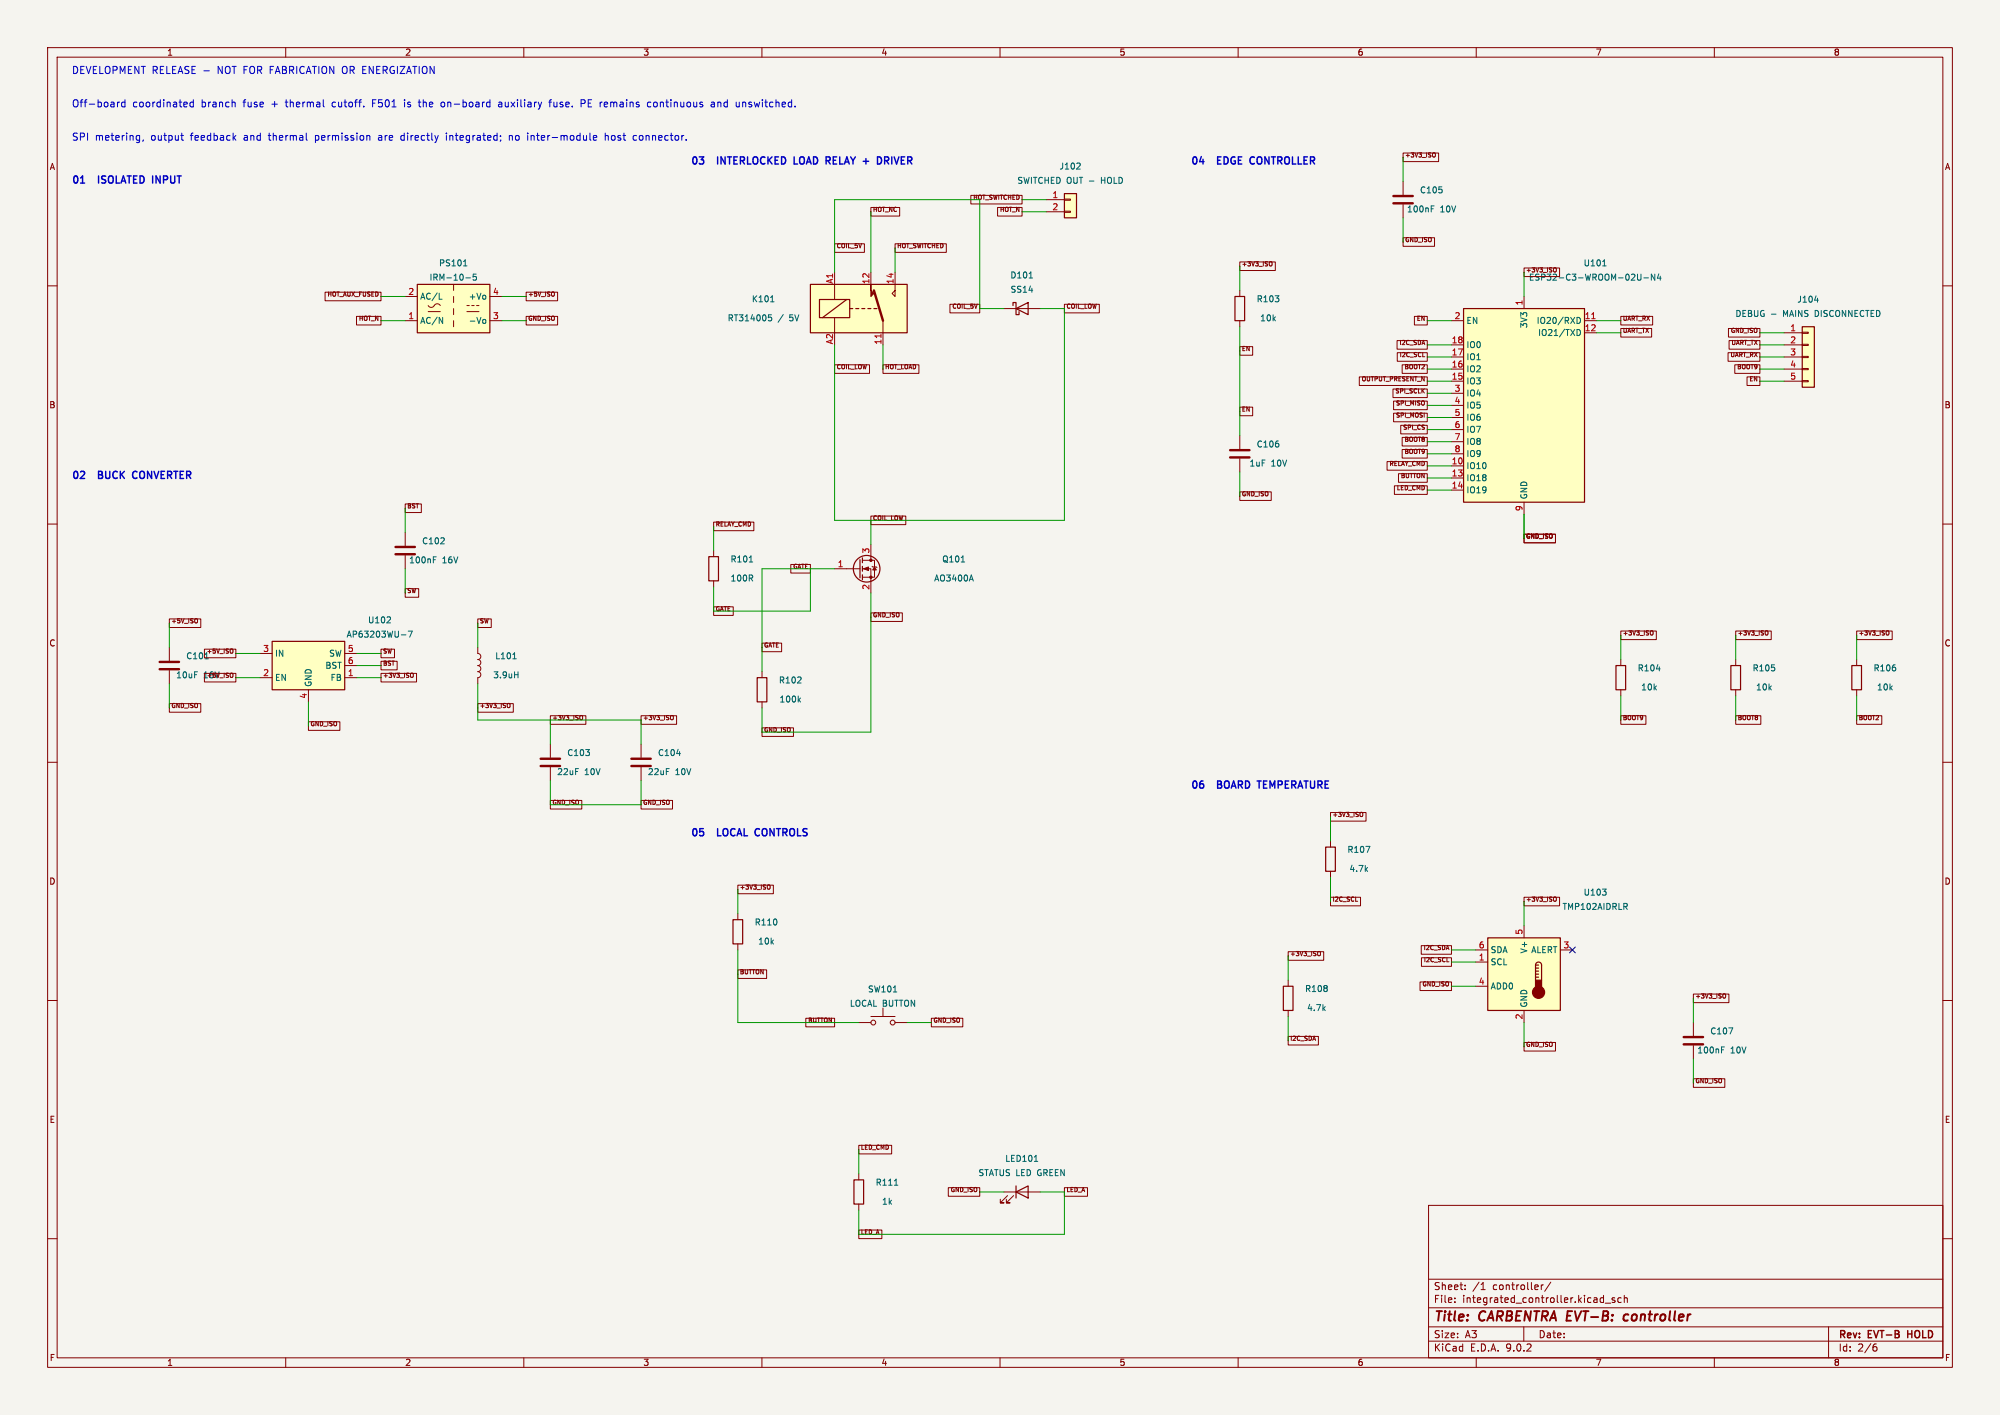
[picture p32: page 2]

DEVELOPMENT RELEASE - NOT FOR FABRICATION OR ENERGIZATION

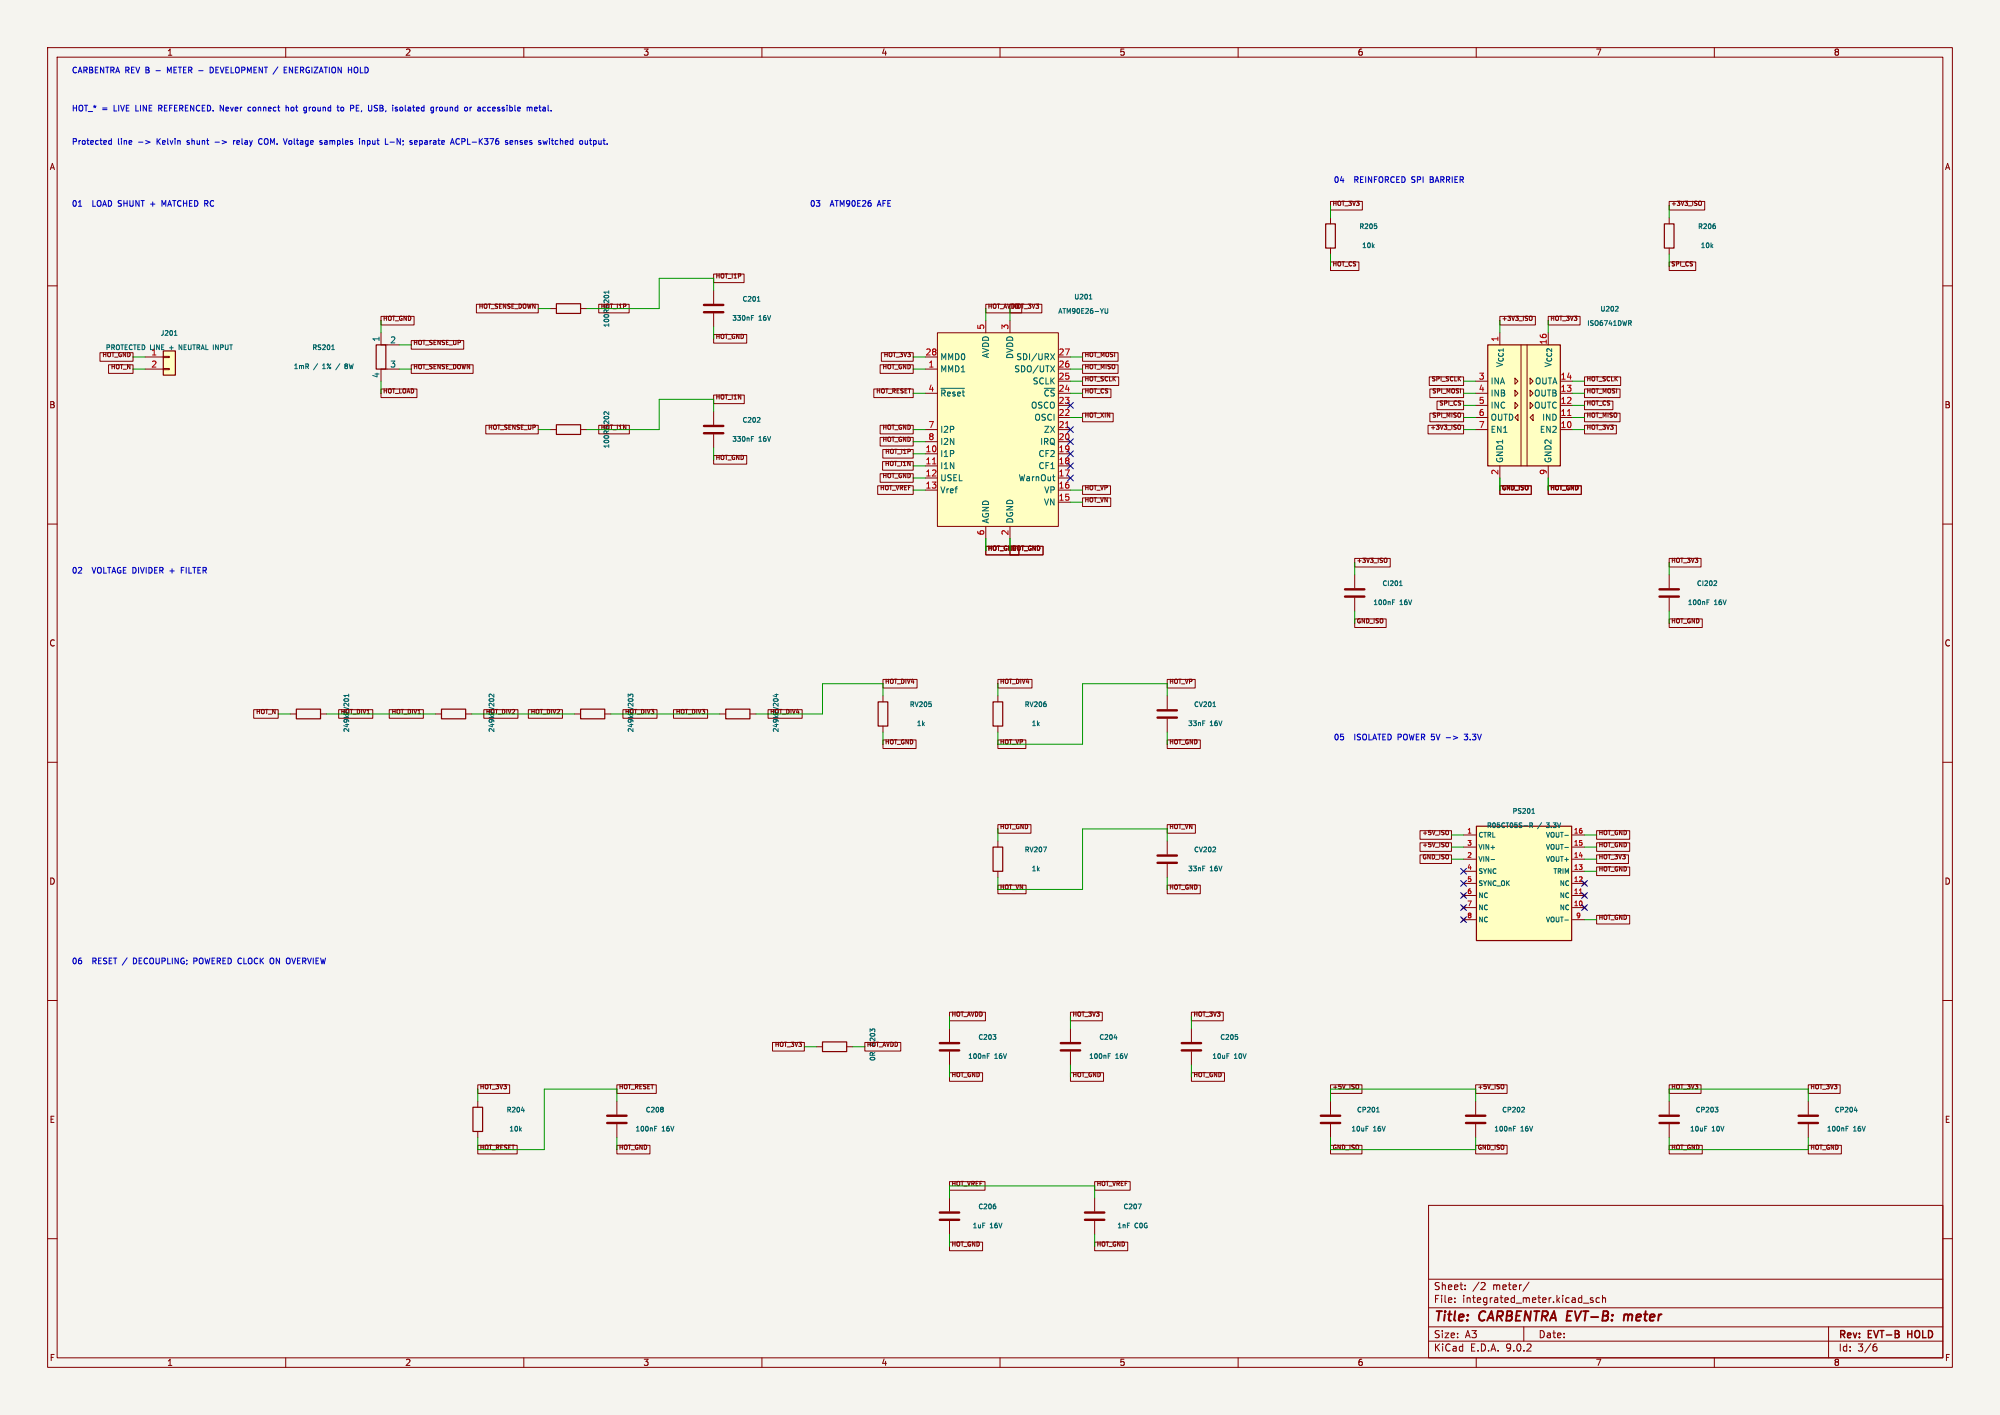
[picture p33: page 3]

CARBENTRA REV B - METER - DEVELOPMENT / ENERGIZATION HOLD

J201 PROTECTED LINE + NEUTRAL INPUT

2 SDI/URX 27 SDO/UTX 26 SCLK 25 ~{CS} 24 OSCO 23 OSCI 22 ZX 21

Id: 3/6 Title: CARBENTRA EVT-B: meter File: integrated_meter.kicad_sch Sheet: /2 meter/

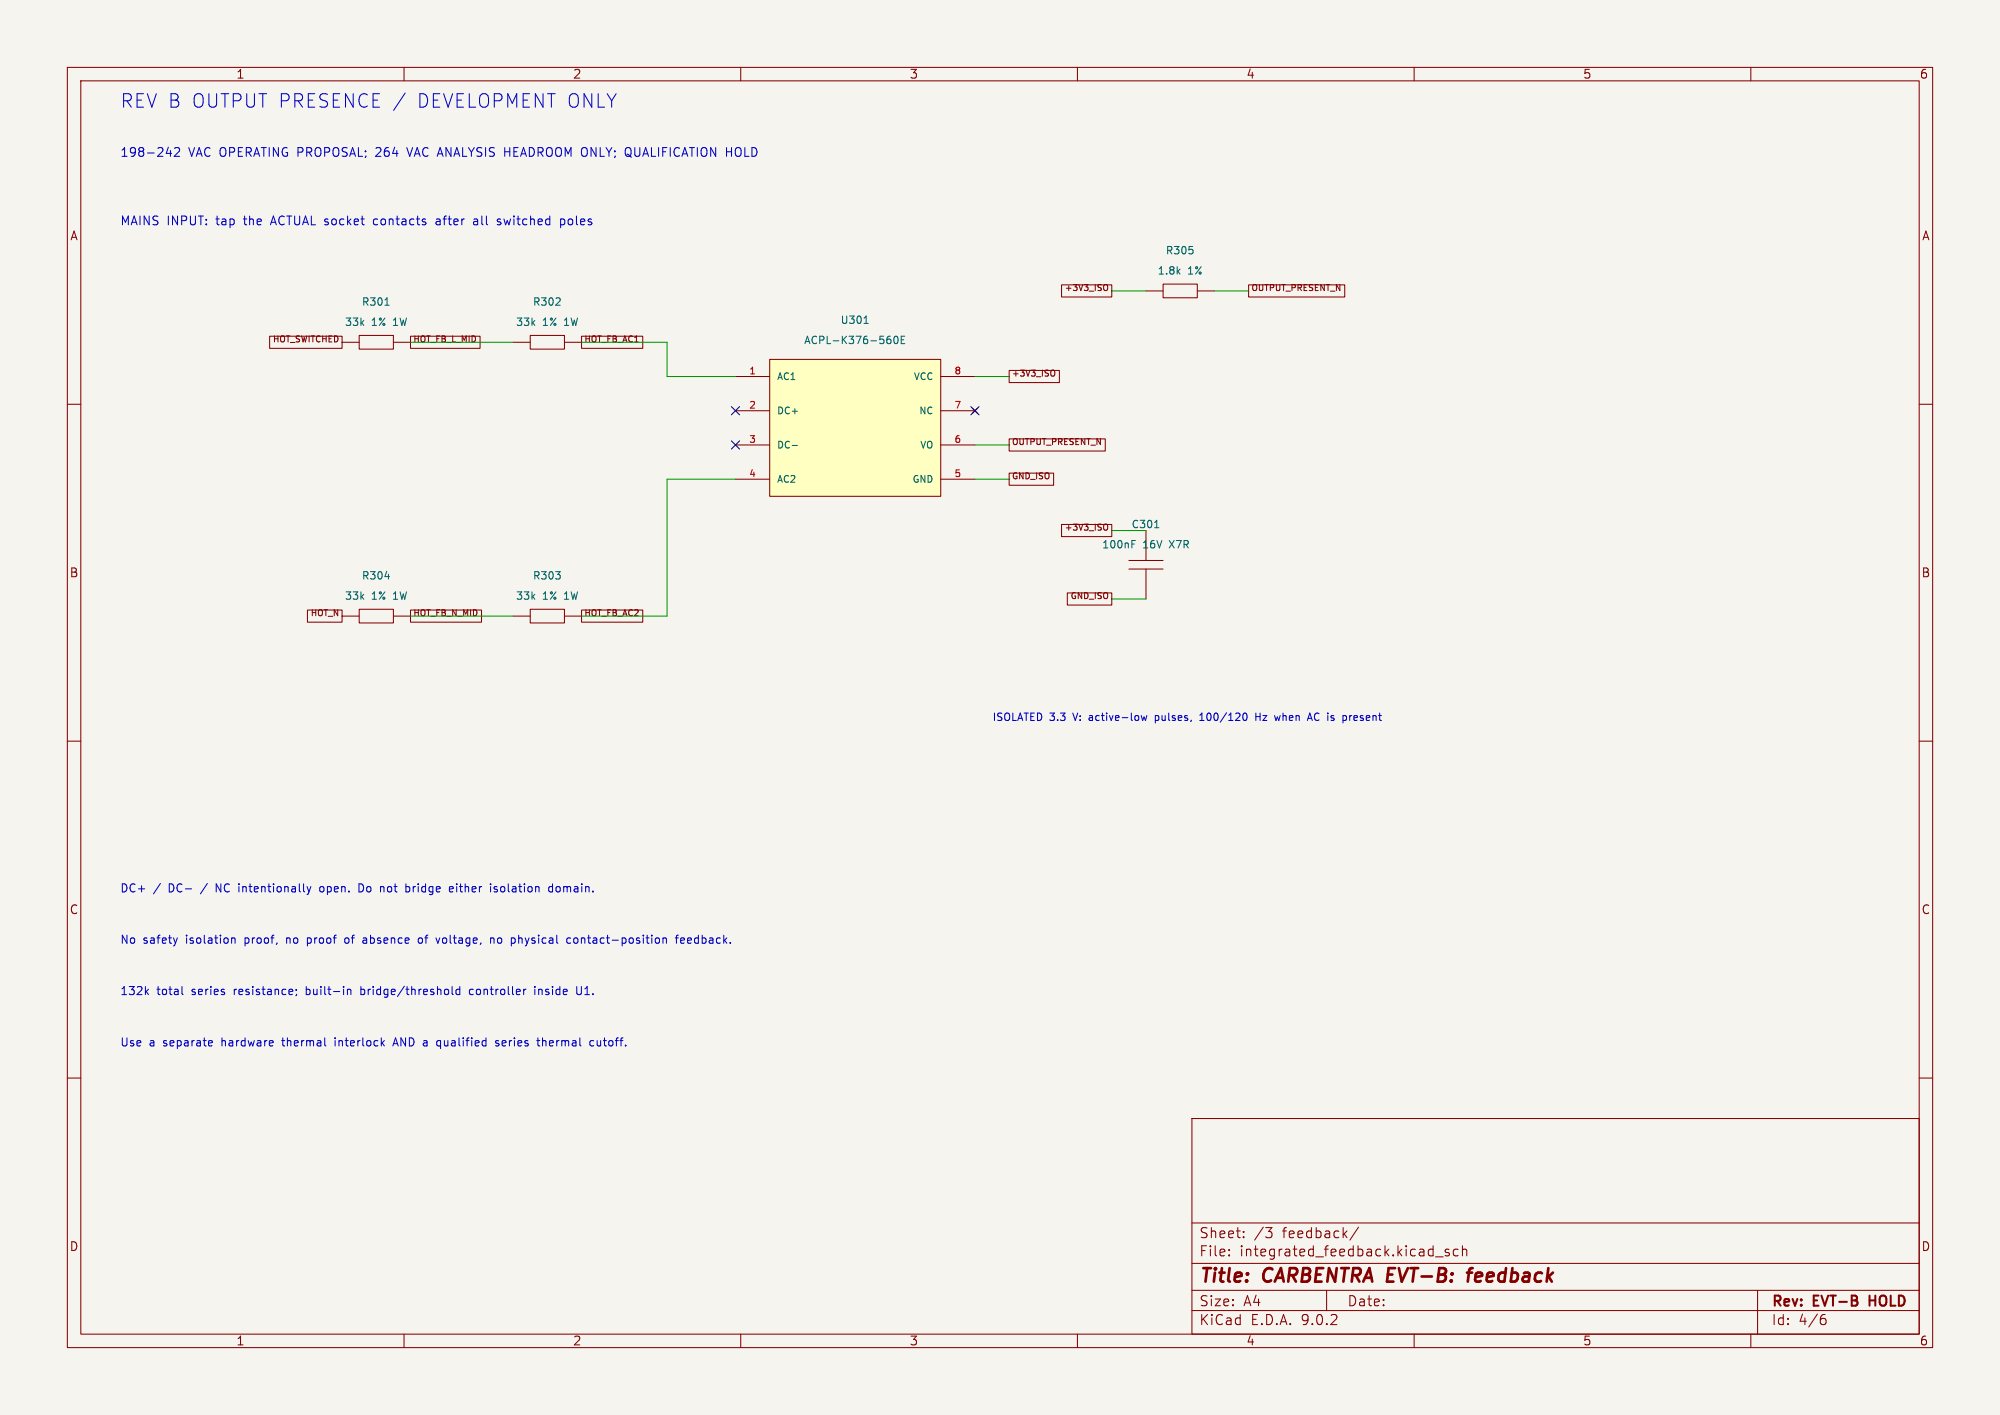
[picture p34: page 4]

File: integrated_feedback.kicad_sch Sheet: /3 feedback/
Id: 4/6 Title: CARBENTRA EVT-B: feedback

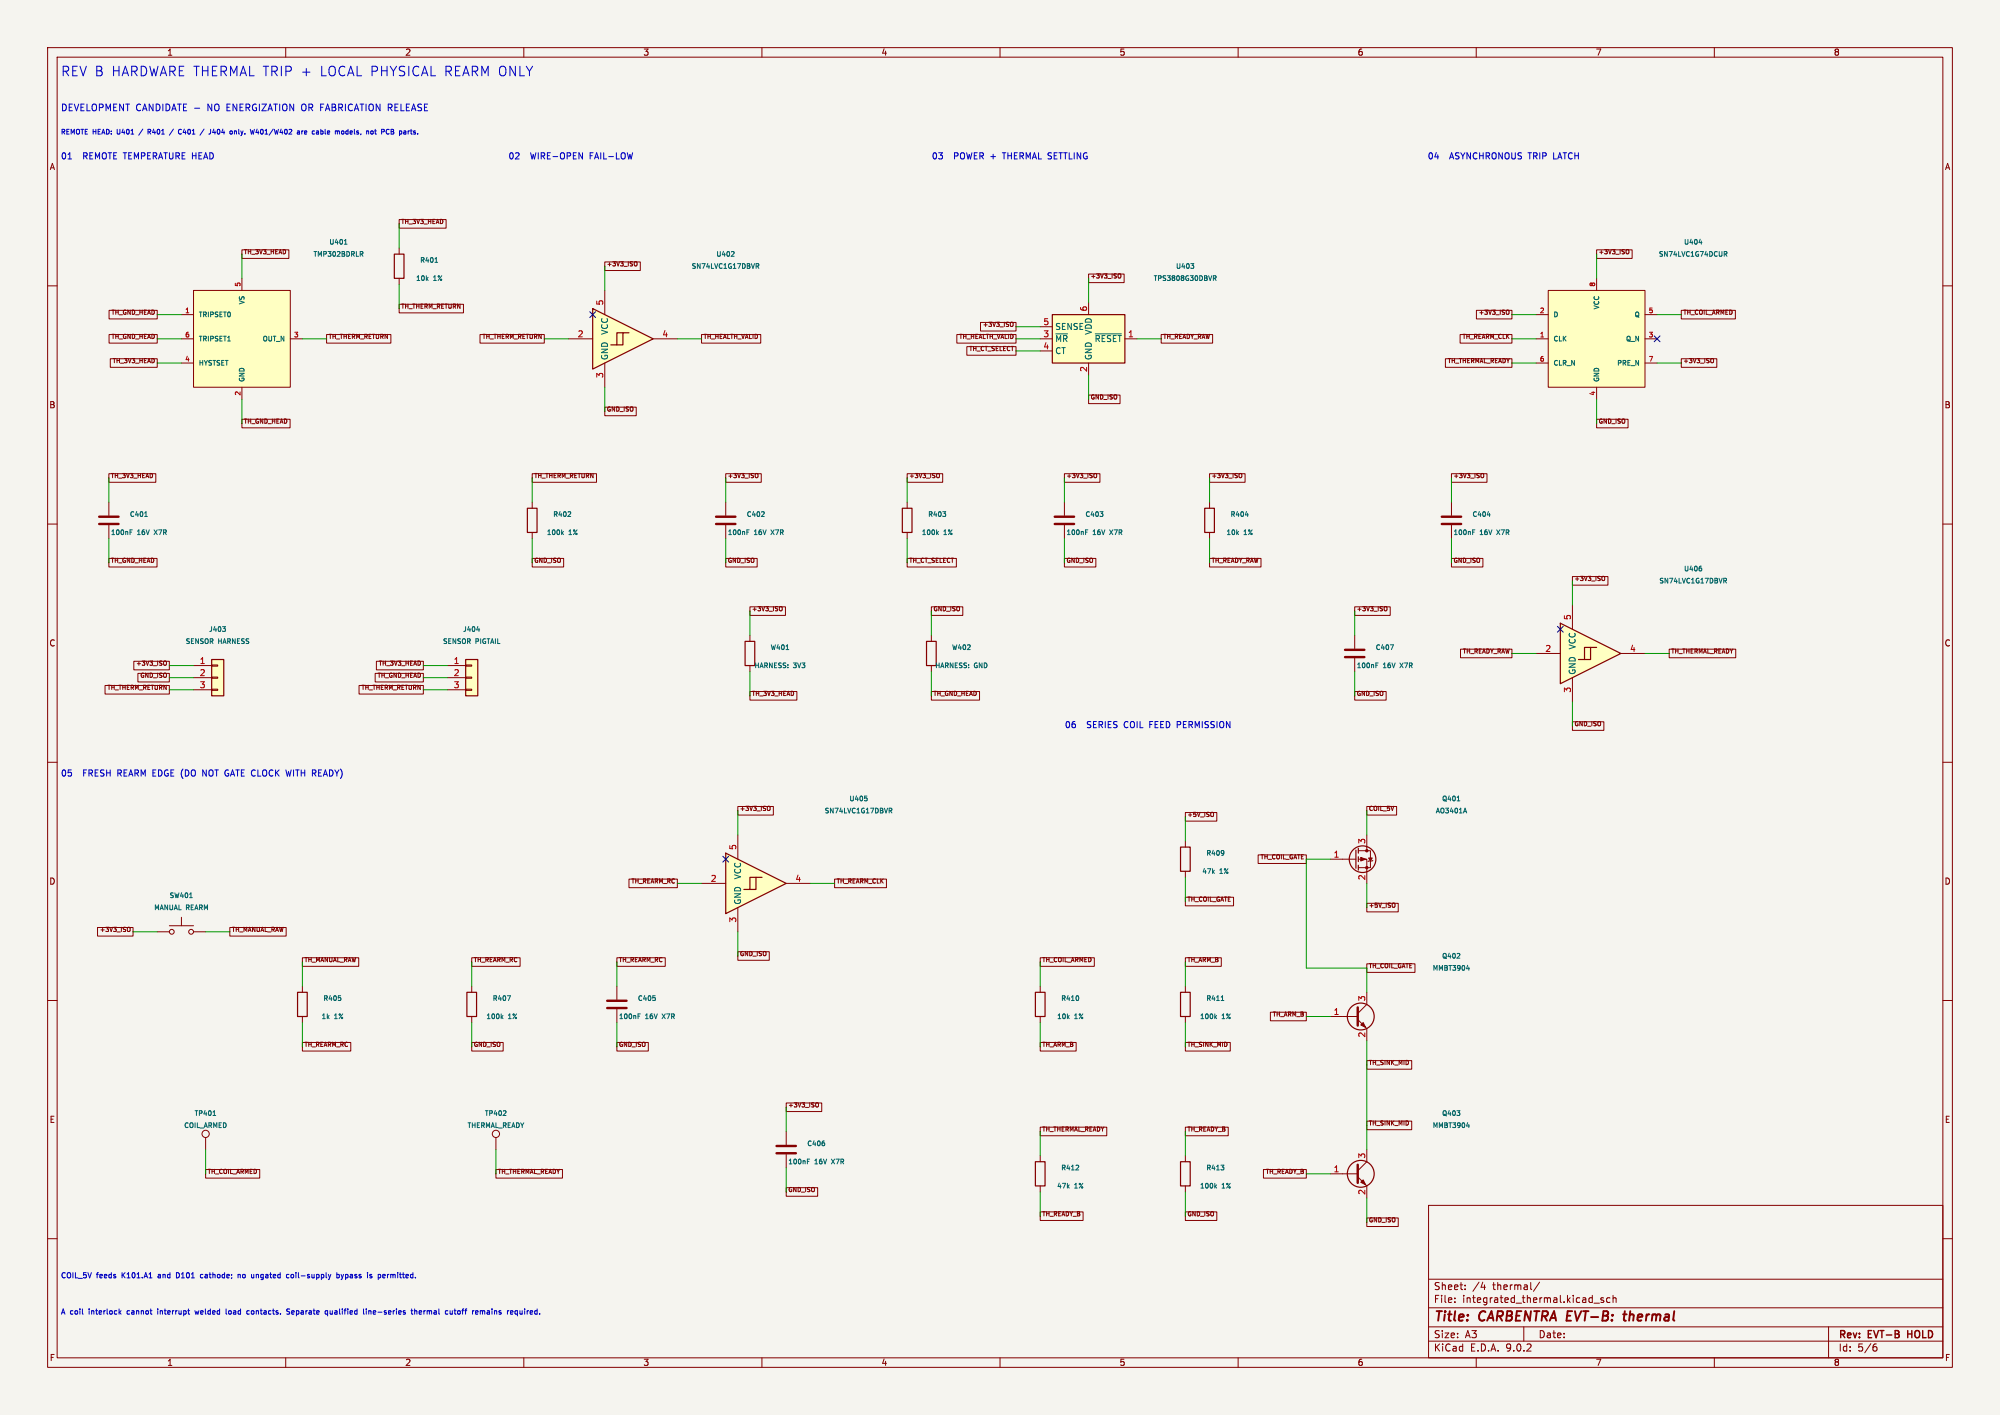
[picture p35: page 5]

DEVELOPMENT CANDIDATE - NO ENERGIZATION OR FABRICATION RELEASE

Id: 5/6 Title: CARBENTRA EVT-B: thermal File: integrated_thermal.kicad_sch Sheet: /4 thermal/

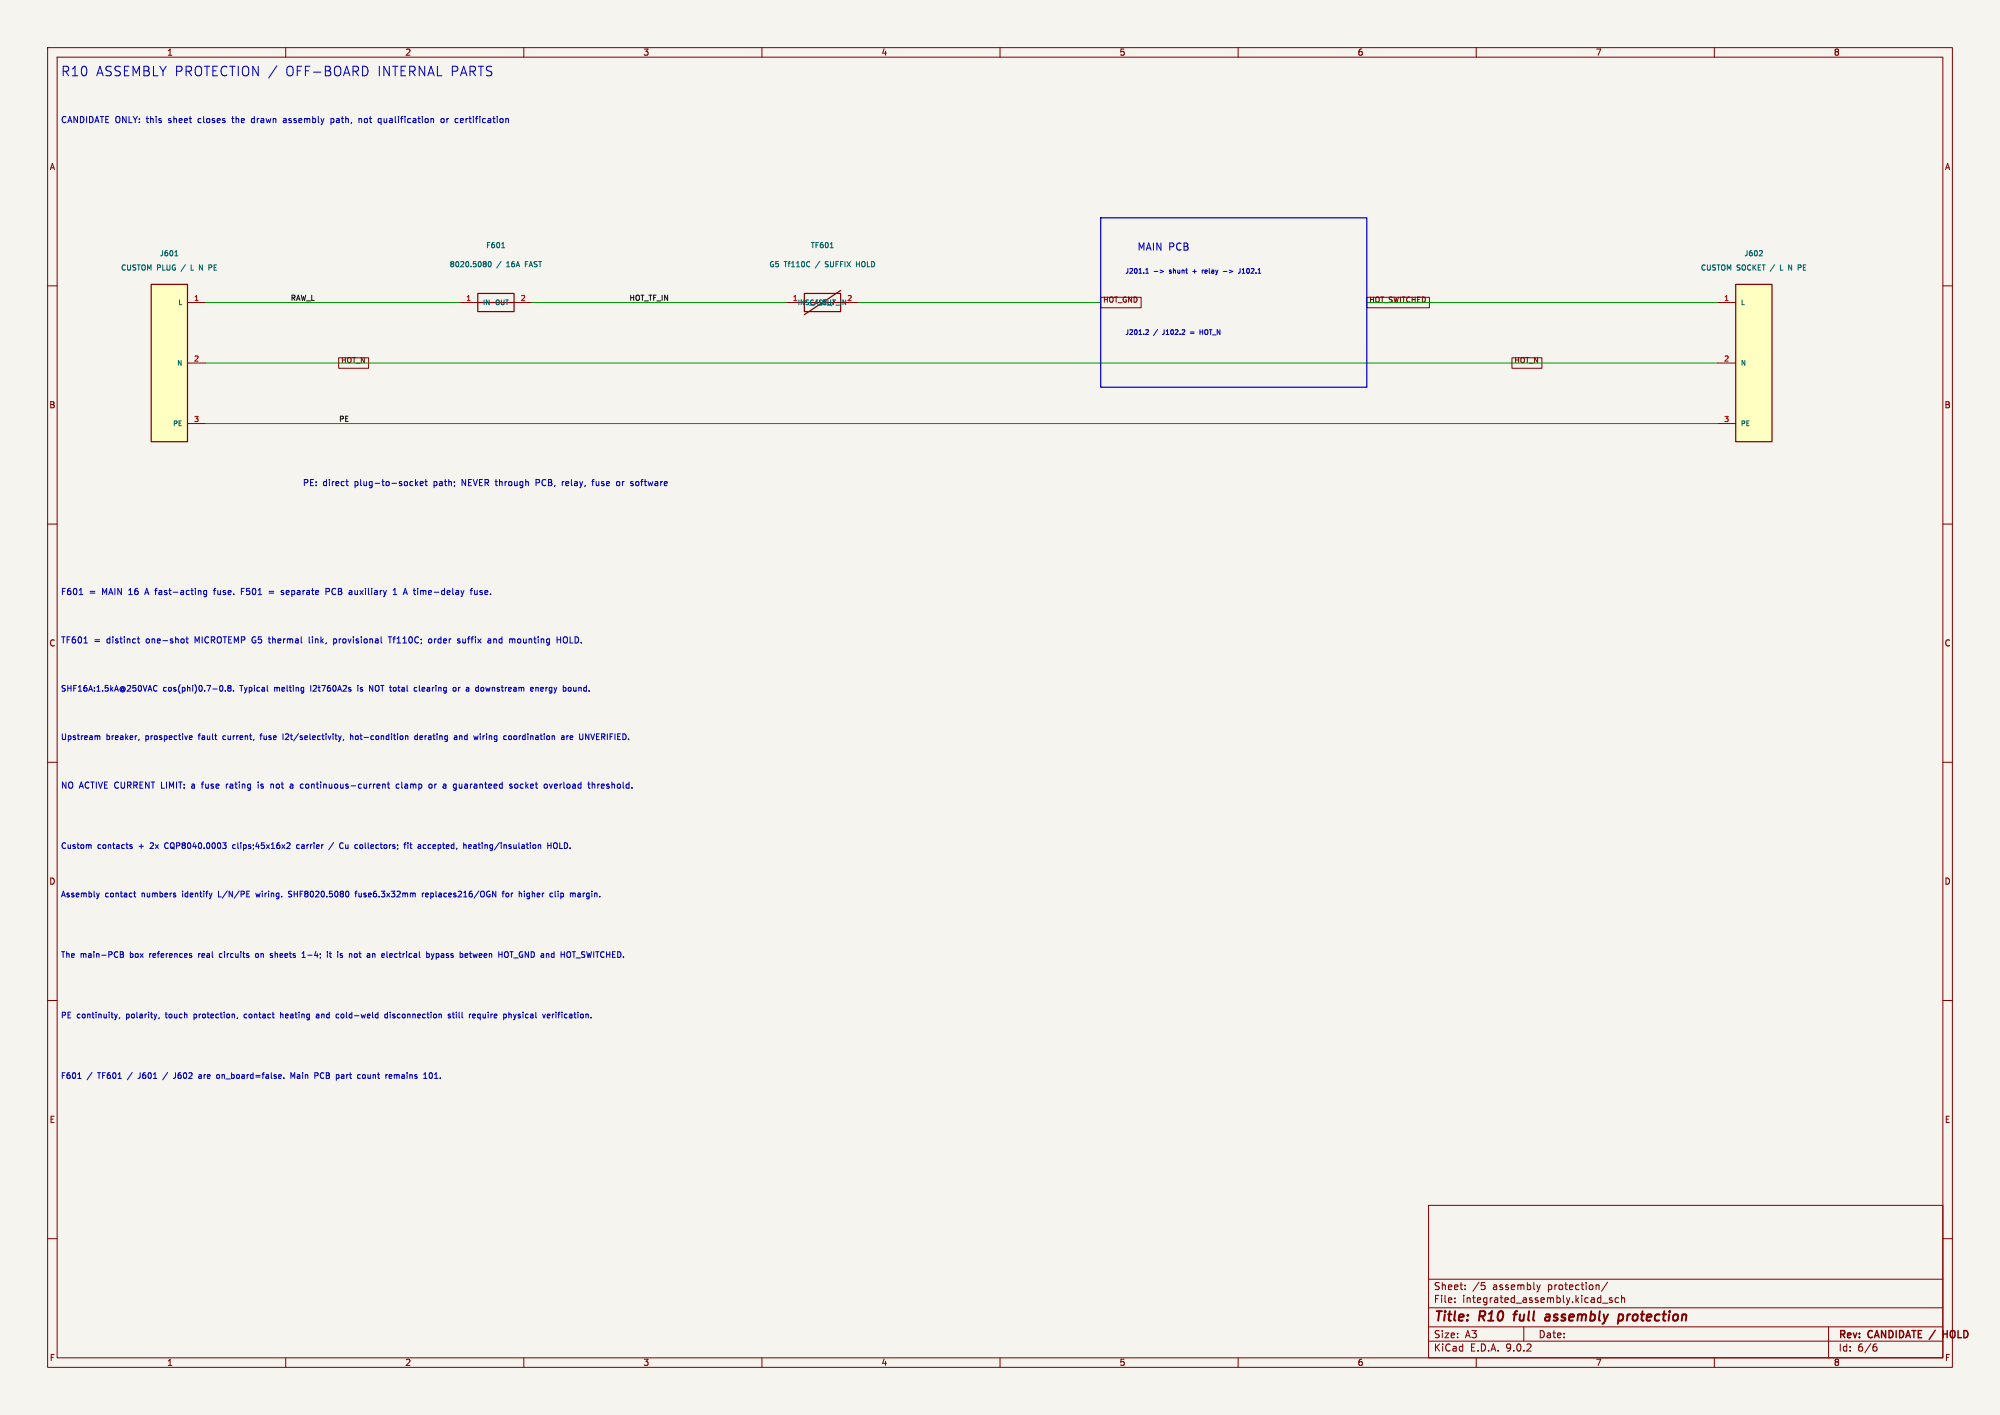
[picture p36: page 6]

Id: 6/6 Title: R10 full assembly protection

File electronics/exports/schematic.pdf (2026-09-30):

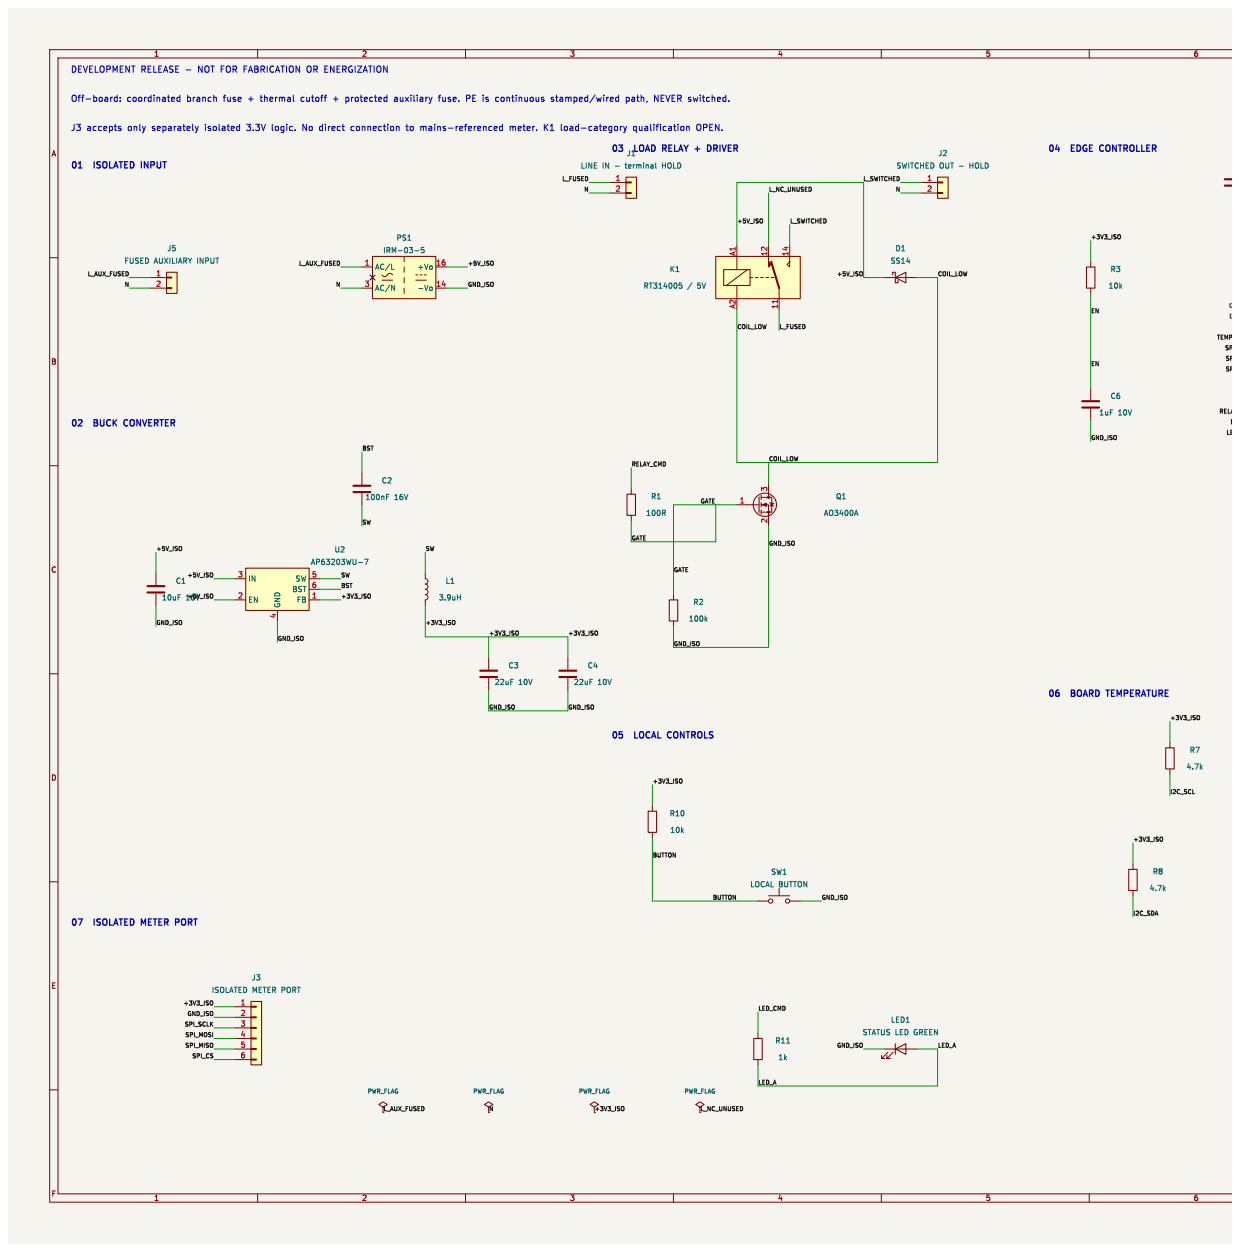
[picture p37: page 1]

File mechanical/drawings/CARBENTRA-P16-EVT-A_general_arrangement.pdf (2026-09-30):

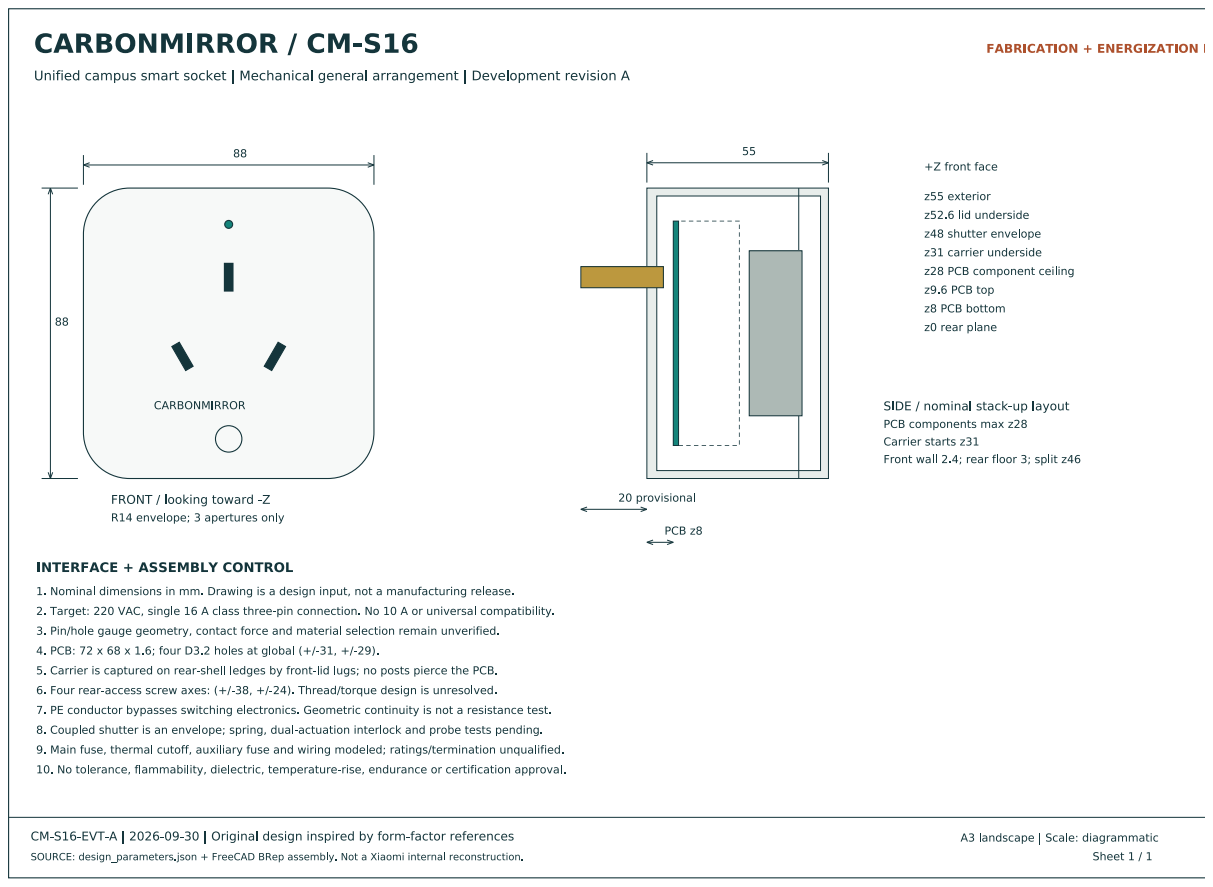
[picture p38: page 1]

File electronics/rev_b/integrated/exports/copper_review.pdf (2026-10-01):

CARBENTRA | CARBENTRA-P16-EVT-B | F.Cu | DEVELOPMENT HOLD

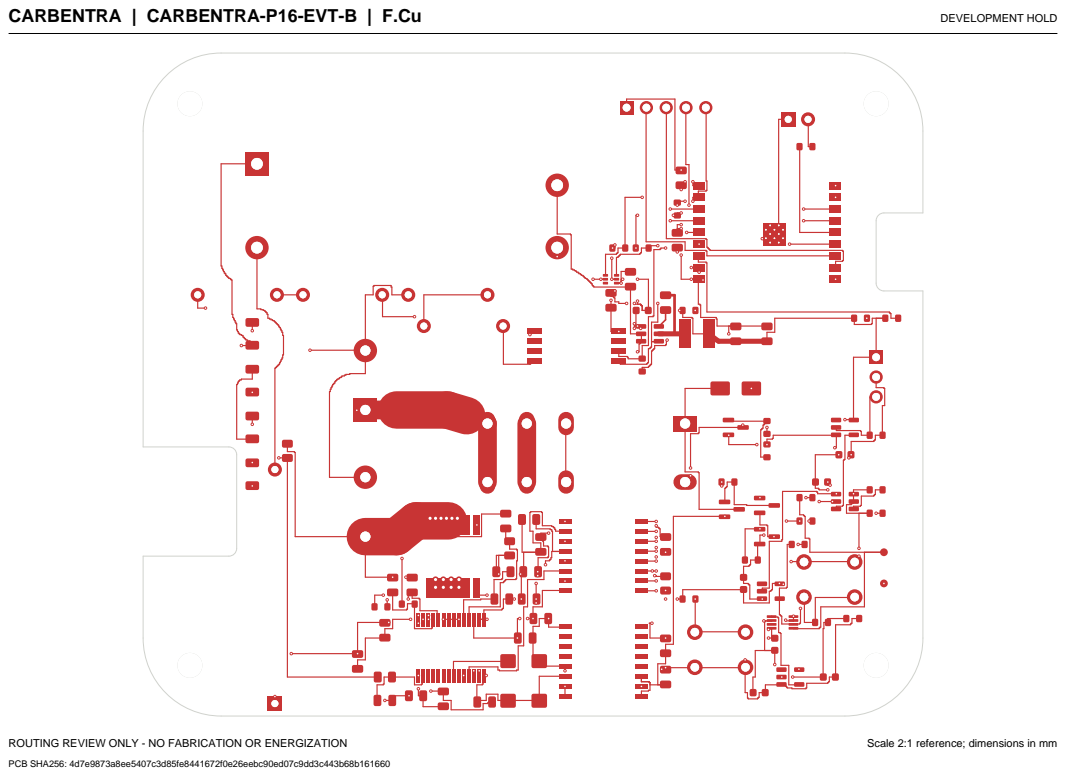
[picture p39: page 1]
ROUTING REVIEW ONLY - NO FABRICATION OR ENERGIZATION; Scale 2:1 reference; dimensions in mm; PCB SHA256: 4d7e9873a8ee5407c3d85fe8441672f0e26eebc90ed07c9dd3c443b68b161660

CARBENTRA | CARBENTRA-P16-EVT-B | In1.Cu | DEVELOPMENT HOLD

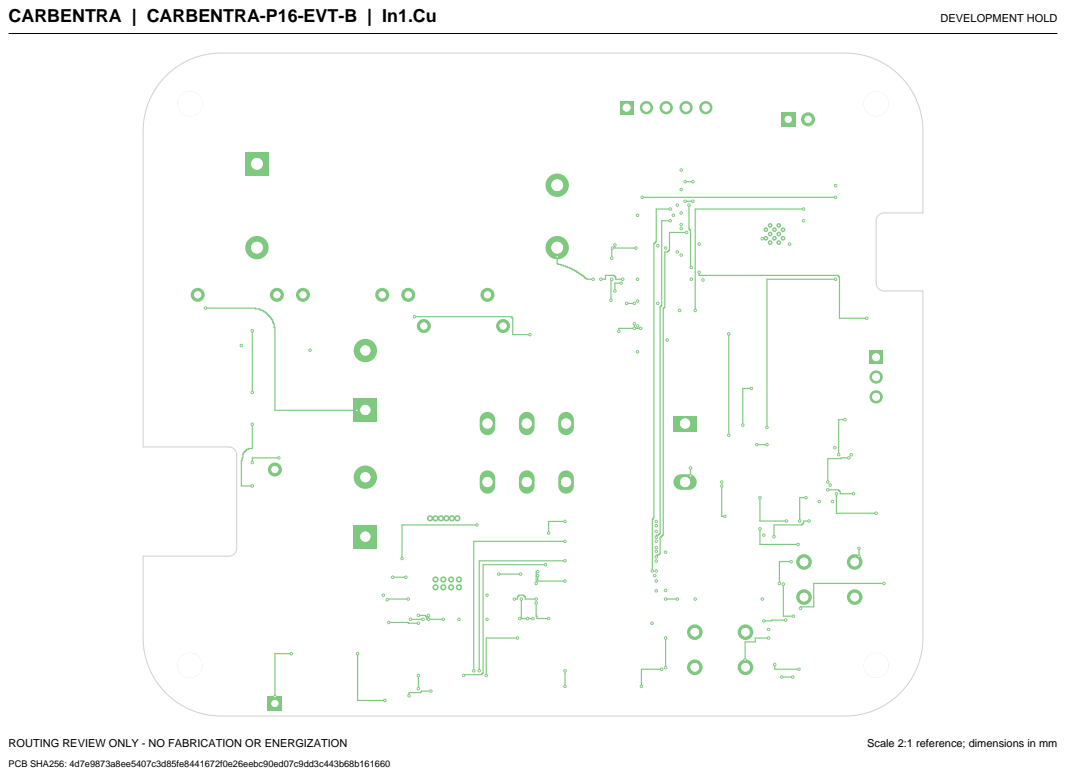
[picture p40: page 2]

CARBENTRA | CARBENTRA-P16-EVT-B | In2.Cu | DEVELOPMENT HOLD

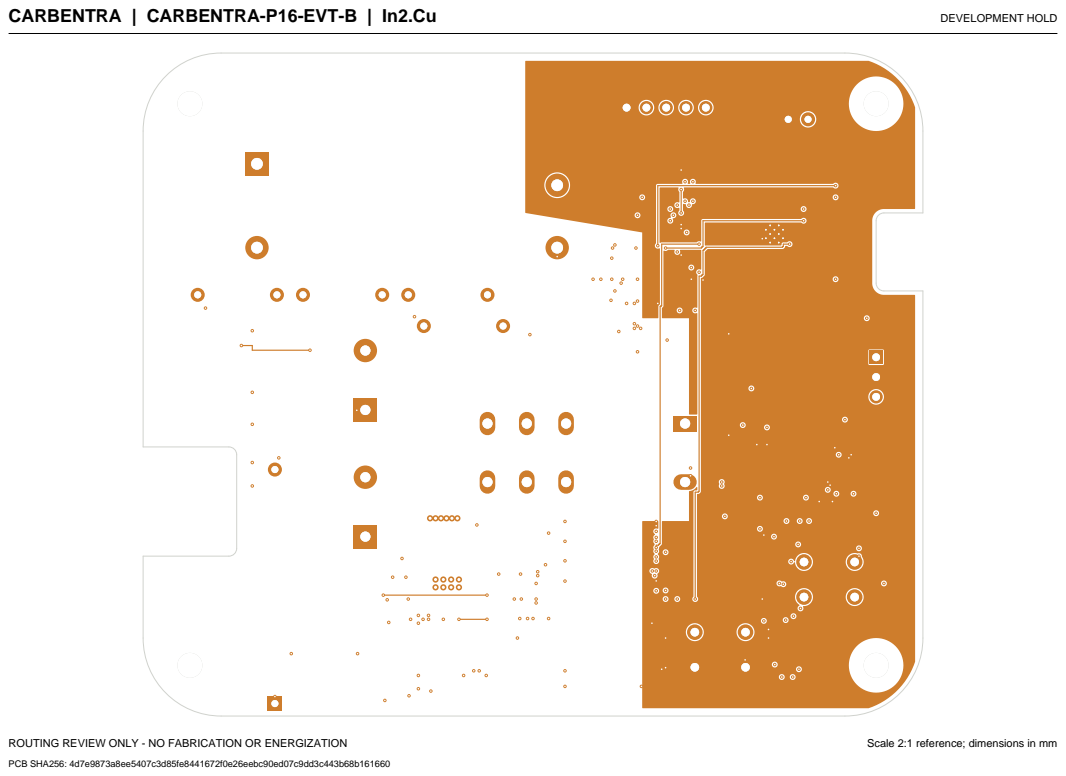
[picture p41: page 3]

CARBENTRA | CARBENTRA-P16-EVT-B | B.Cu | DEVELOPMENT HOLD






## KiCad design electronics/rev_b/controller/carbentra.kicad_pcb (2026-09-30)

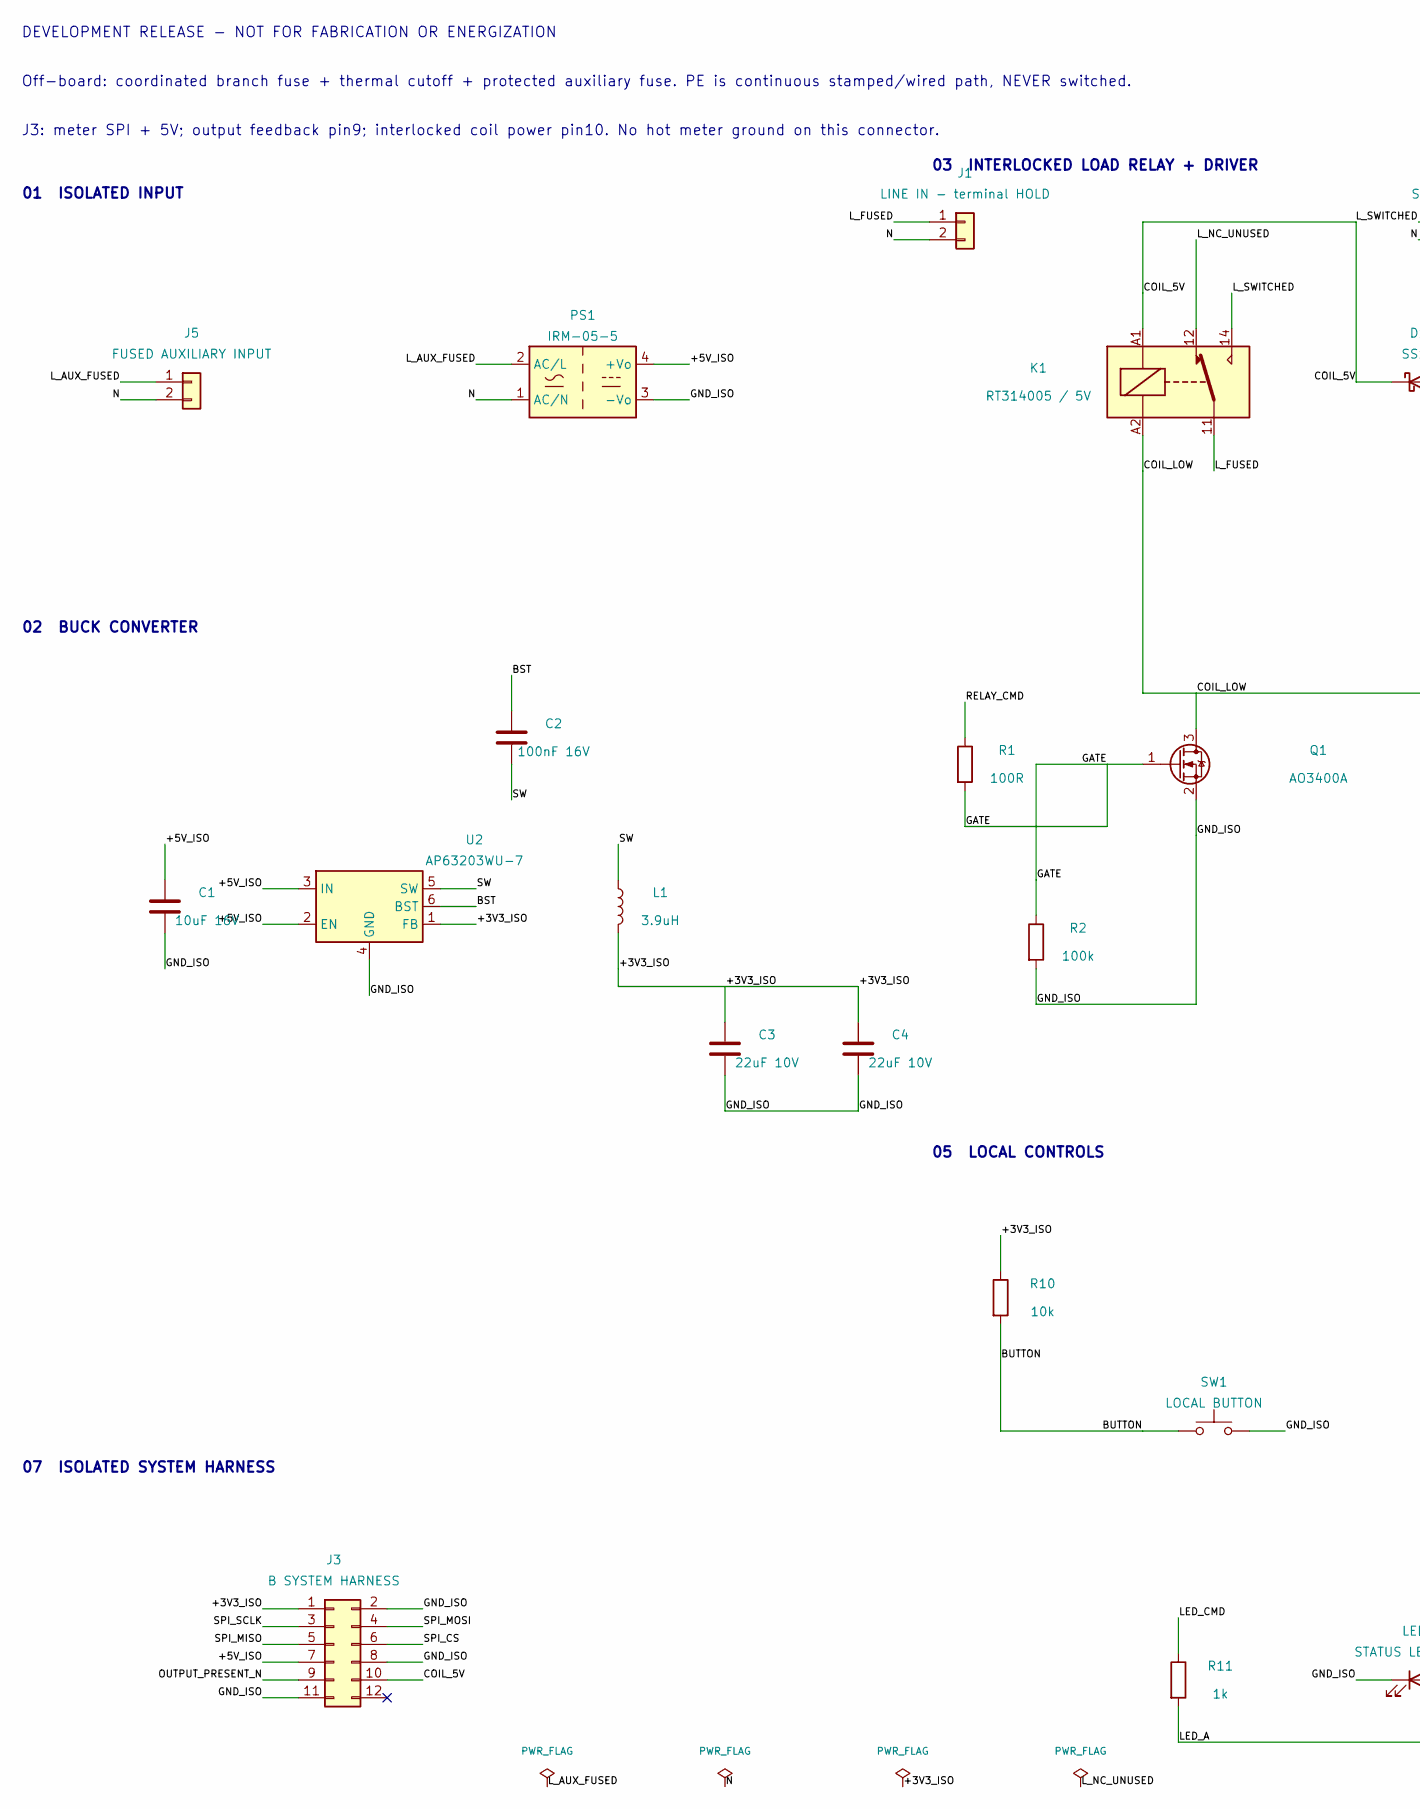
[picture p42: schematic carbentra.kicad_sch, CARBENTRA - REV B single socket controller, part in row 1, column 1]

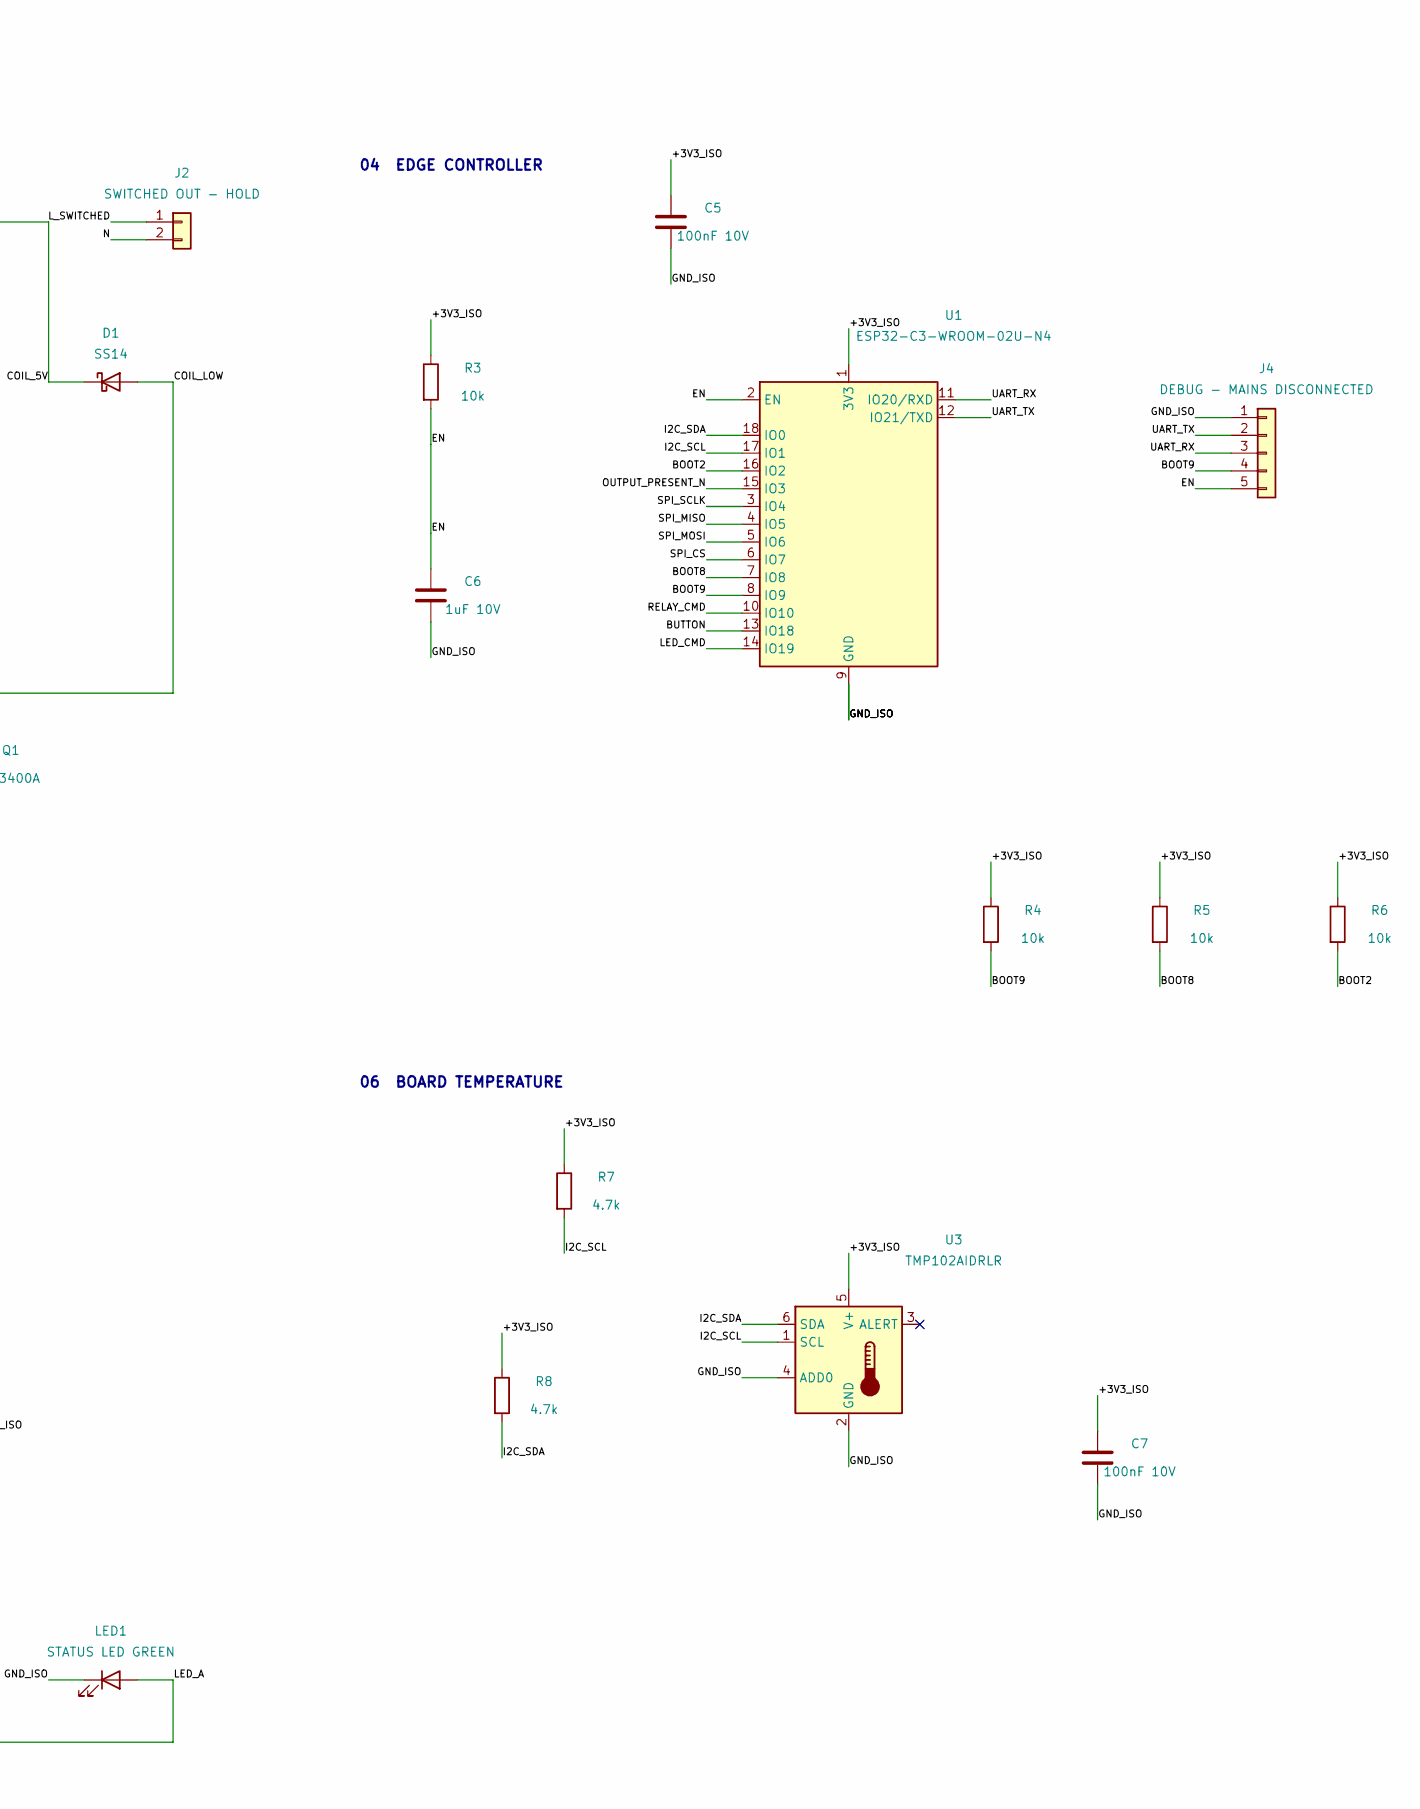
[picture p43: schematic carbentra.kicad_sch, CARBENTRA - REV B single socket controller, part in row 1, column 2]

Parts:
C1: 10uF 16V; C_0805_2012Metric
C2: 100nF 16V; C_0805_2012Metric
C3, C4: 22uF 10V; C_0805_2012Metric
C5, C7: 100nF 10V; C_0805_2012Metric
C6: 1uF 10V; C_0805_2012Metric
D1: SS14; D_SMA
J1: LINE IN - terminal HOLD; TerminalBlock_Phoenix_MKDS-3-2-5.08_1x02_P5.08mm_Horizontal
J2: SWITCHED OUT - HOLD; TerminalBlock_Phoenix_MKDS-3-2-5.08_1x02_P5.08mm_Horizontal
J3: B SYSTEM HARNESS; PinHeader_2x06_P2.54mm_Vertical
J4: DEBUG - MAINS DISCONNECTED; PinHeader_1x05_P2.54mm_Vertical
J5: FUSED AUXILIARY INPUT; TerminalBlock_Phoenix_MKDS-3-2-5.08_1x02_P5.08mm_Horizontal
K1: RT314005 / 5V; Relay_SPDT_Schrack-RT1-16A-FormC_RM5mm
L1: 3.9uH; L_Bourns-SRN4018
LED1: STATUS LED GREEN; LED_D3.0mm
PS1: IRM-05-5; Converter_ACDC_MeanWell_IRM-05-xx_THT
Q1: AO3400A; SOT-23
R1: 100R; R_0603_1608Metric
R2: 100k; R_0603_1608Metric
R3, R4, R5, R6, R10: 10k; R_0603_1608Metric
R7, R8: 4.7k; R_0603_1608Metric
R11: 1k; R_0603_1608Metric
SW1: LOCAL BUTTON; SW_PUSH_6mm
U1: ESP32-C3-WROOM-02U-N4; ESP32-C3-WROOM-02U
U2: AP63203WU-7; TSOT-23-6
U3: TMP102AIDRLR; SOT-563

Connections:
+3V3_ISO: C3.1, C4.1, C5.1, C7.1, J3.1, L1.2, R3.1, R4.1, R5.1, R6.1, R7.1, R8.1, R10.1, U1.1 (3V3), U2.1 (FB), U3.5 (V+)
+5V_ISO: C1.1, J3.7, PS1.4 (+Vo), U2.2 (EN), U2.3 (IN)
BOOT2: R6.2, U1.16 (IO2)
BOOT8: R5.2, U1.7 (IO8)
BOOT9: J4.4, R4.2, U1.8 (IO9)
BST: C2.1, U2.6 (BST)
BUTTON: R10.2, SW1.1, U1.13 (IO18)
COIL_5V: D1.1 (K), J3.10, K1.A1
COIL_LOW: D1.2 (A), K1.A2, Q1.3 (D)
EN: C6.1, J4.5, R3.2, U1.2 (EN)
GATE: Q1.1 (G), R1.2, R2.1
GND_ISO: C1.2, C3.2, C4.2, C5.2, C6.2, C7.2, J3.2, J3.8, J3.11, J4.1, LED1.1 (K), PS1.3 (-Vo), Q1.2 (S), R2.2, SW1.2, U1.9 (GND), U1.19 (GND), U2.4 (GND), U3.2 (GND), U3.4 (ADD0)
I2C_SCL: R7.2, U1.17 (IO1), U3.1 (SCL)
I2C_SDA: R8.2, U1.18 (IO0), U3.6 (SDA)
LED_A: LED1.2 (A), R11.2
LED_CMD: R11.1, U1.14 (IO19)
L_AUX_FUSED: J5.1, PS1.2 (AC/L)
L_FUSED: J1.1, K1.11
L_NC_UNUSED: K1.12
L_SWITCHED: J2.1, K1.14
N: J1.2, J2.2, J5.2, PS1.1 (AC/N)
OUTPUT_PRESENT_N: J3.9, U1.15 (IO3)
RELAY_CMD: R1.1, U1.10 (IO10)
SPI_CS: J3.6, U1.6 (IO7)
SPI_MISO: J3.5, U1.4 (IO5)
SPI_MOSI: J3.4, U1.5 (IO6)
SPI_SCLK: J3.3, U1.3 (IO4)
SW: C2.2, L1.1, U2.5 (SW)
UART_RX: J4.3, U1.11 (IO20/RXD)
UART_TX: J4.2, U1.12 (IO21/TXD)

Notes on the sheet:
DEVELOPMENT RELEASE - NOT FOR FABRICATION OR ENERGIZATION
Off-board: coordinated branch fuse + thermal cutoff + protected auxiliary fuse. PE is continuous stamped/wired path, NEVER switched.
J3: meter SPI + 5V; output feedback pin9; interlocked coil power pin10. No hot meter ground on this connector.
01 ISOLATED INPUT
02 BUCK CONVERTER
03 INTERLOCKED LOAD RELAY + DRIVER
04 EDGE CONTROLLER
05 LOCAL CONTROLS
06 BOARD TEMPERATURE
07 ISOLATED SYSTEM HARNESS

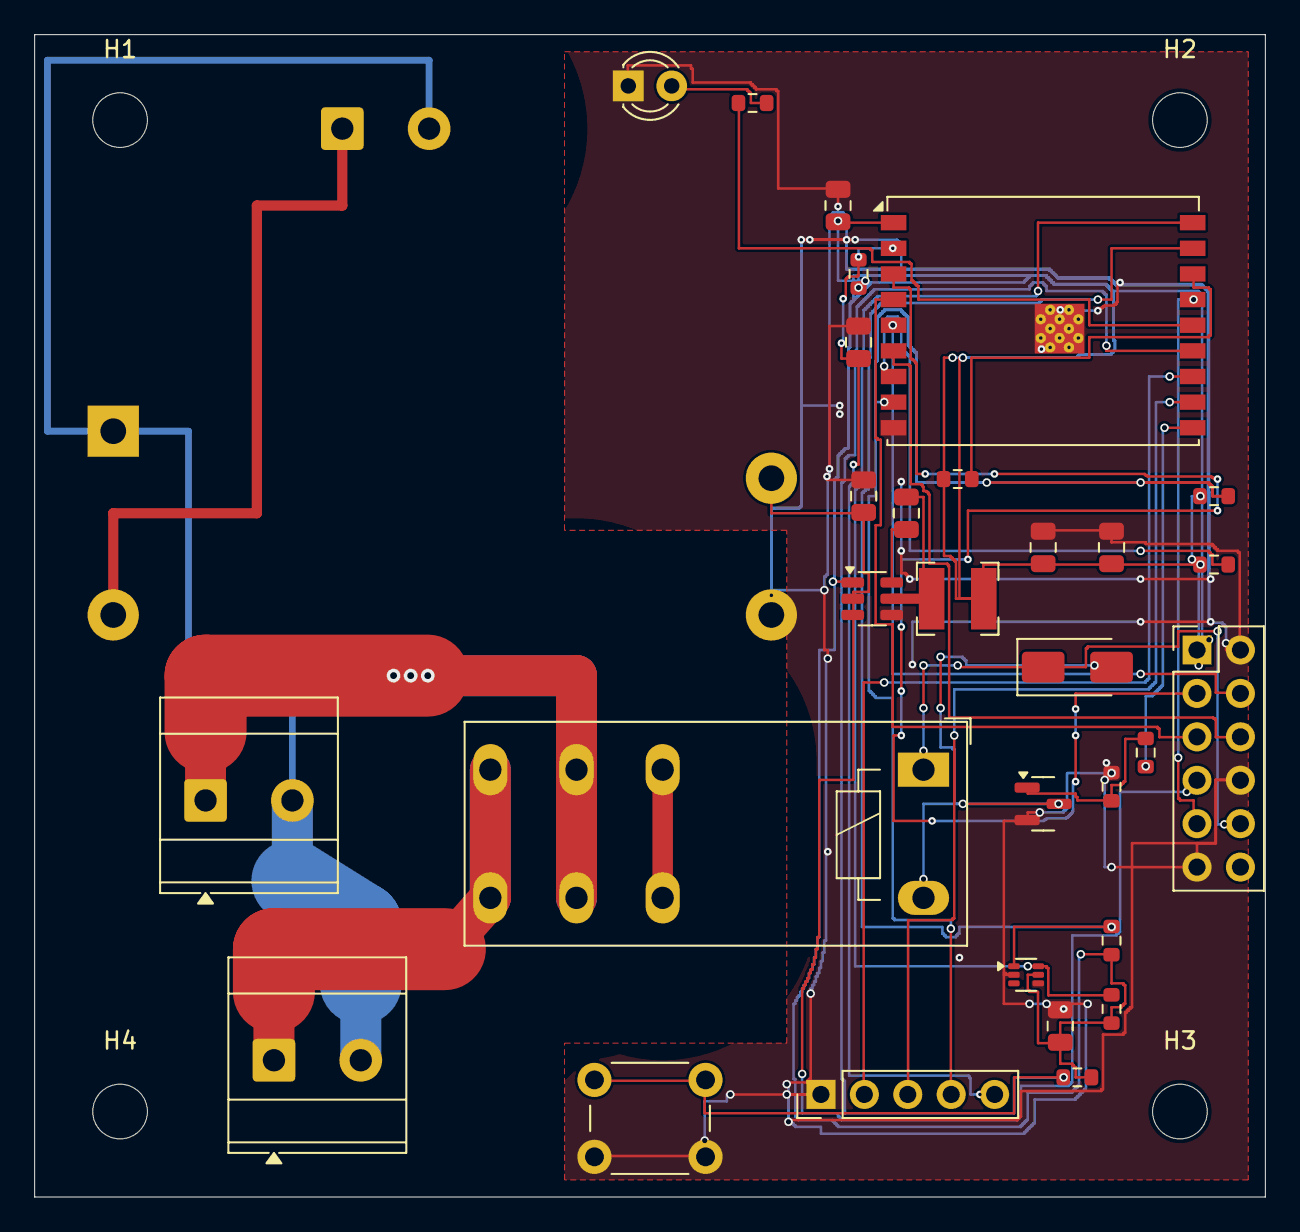
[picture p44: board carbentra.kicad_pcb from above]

Board: 2 copper layers, 72.0 x 68.0 mm, 36 parts (0 on the bottom side), 29 nets.

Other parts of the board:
H1, H2, H3, H4: MountingHole_3.2mm_M3

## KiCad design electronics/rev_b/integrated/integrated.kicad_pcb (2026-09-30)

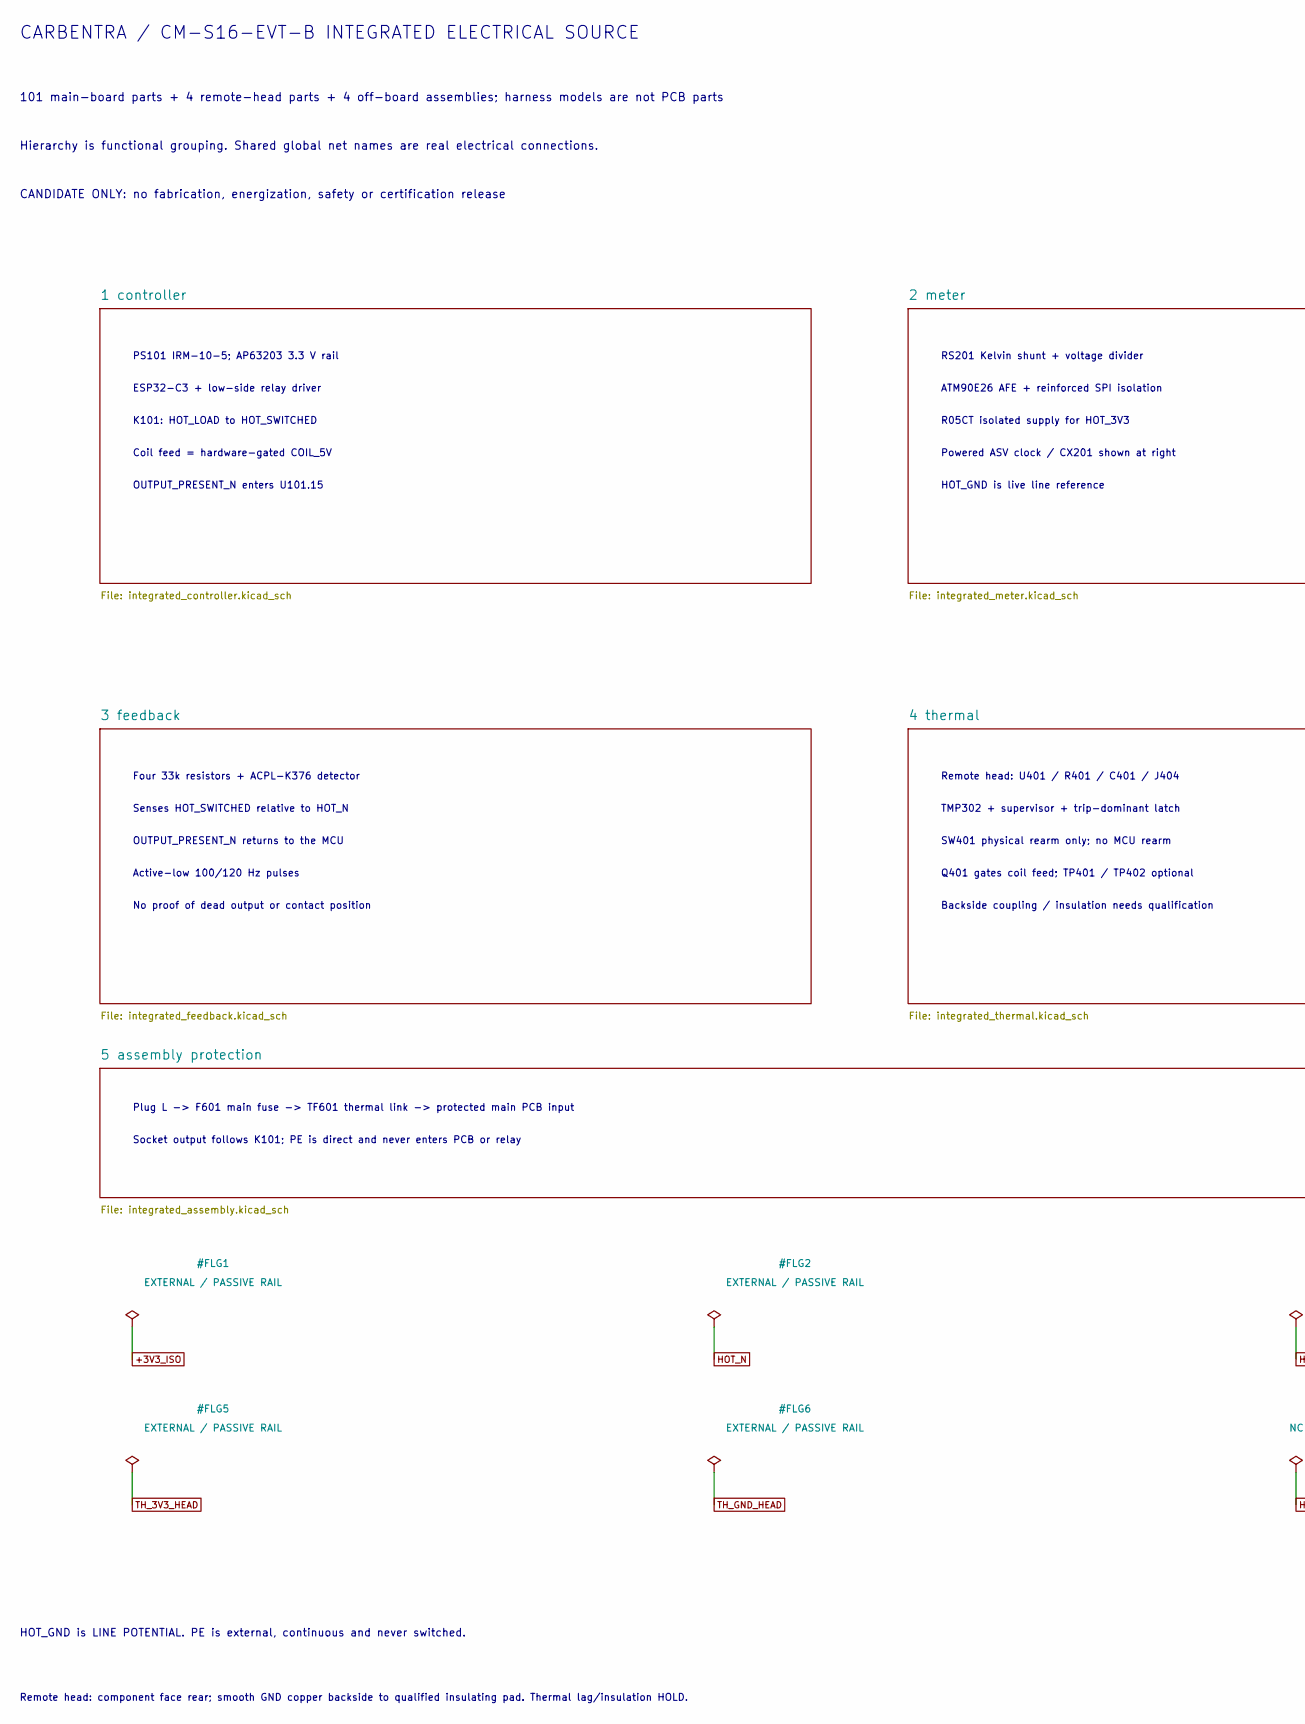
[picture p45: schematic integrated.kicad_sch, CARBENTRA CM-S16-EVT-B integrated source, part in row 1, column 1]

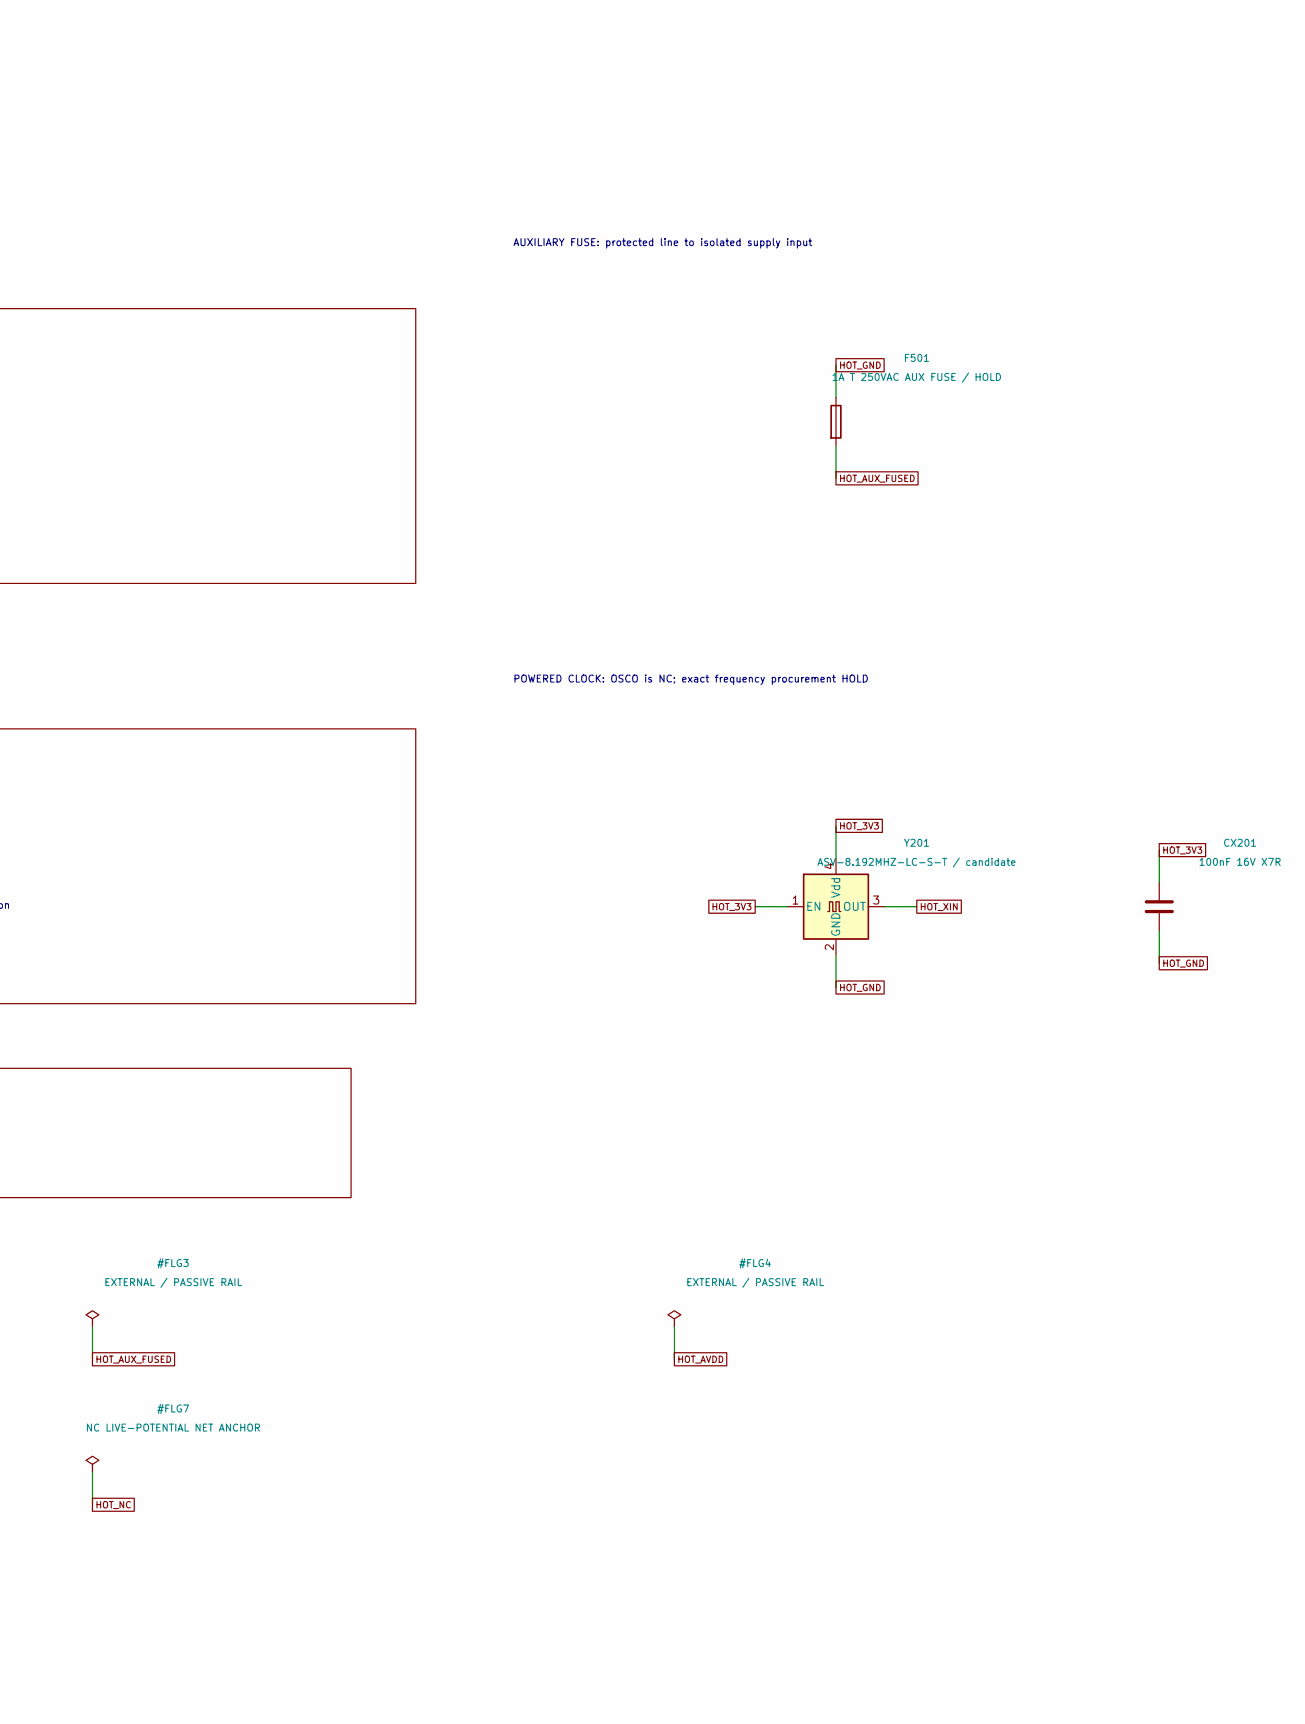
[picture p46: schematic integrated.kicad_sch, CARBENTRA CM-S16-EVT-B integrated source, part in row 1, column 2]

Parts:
CX201: 100nF 16V X7R; C_0805_2012Metric
F501: 1A T 250VAC AUX FUSE / HOLD; Fuse_215_Axial_P30mm
Y201: ASV-8.192MHZ-LC-S-T / candidate; Oscillator_SMD_Abracon_ASV-4Pin_7.0x5.1mm

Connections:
HOT_3V3: CX201.1, Y201.1 (EN), Y201.4 (Vdd); also elsewhere on the board
HOT_AUX_FUSED: F501.2; also elsewhere on the board
HOT_GND: CX201.2, F501.1, Y201.2 (GND); also elsewhere on the board
HOT_XIN: Y201.3 (OUT); also elsewhere on the board

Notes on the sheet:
PS101 IRM-10-5; AP63203 3.3 V rail
ESP32-C3 + low-side relay driver
K101: HOT_LOAD to HOT_SWITCHED
Coil feed = hardware-gated COIL_5V
OUTPUT_PRESENT_N enters U101.15
RS201 Kelvin shunt + voltage divider
ATM90E26 AFE + reinforced SPI isolation
R05CT isolated supply for HOT_3V3
Powered ASV clock / CX201 shown at right
HOT_GND is live line reference
Four 33k resistors + ACPL-K376 detector
Senses HOT_SWITCHED relative to HOT_N
OUTPUT_PRESENT_N returns to the MCU
Active-low 100/120 Hz pulses
No proof of dead output or contact position
Remote head: U401 / R401 / C401 / J404
TMP302 + supervisor + trip-dominant latch
SW401 physical rearm only; no MCU rearm
Q401 gates coil feed; TP401 / TP402 optional
Backside coupling / insulation needs qualification
Plug L -> F601 main fuse -> TF601 thermal link -> protected main PCB input
Socket output follows K101; PE is direct and never enters PCB or relay
CARBENTRA / CM-S16-EVT-B INTEGRATED ELECTRICAL SOURCE
101 main-board parts + 4 remote-head parts + 4 off-board assemblies; harness models are not PCB parts
Hierarchy is functional grouping. Shared global net names are real electrical connections.
CANDIDATE ONLY: no fabrication, energization, safety or certification release
AUXILIARY FUSE: protected line to isolated supply input
POWERED CLOCK: OSCO is NC; exact frequency procurement HOLD
HOT_GND is LINE POTENTIAL. PE is external, continuous and never switched.
Remote head: component face rear; smooth GND copper backside to qualified insulating pad. Thermal lag/insulation HOLD.

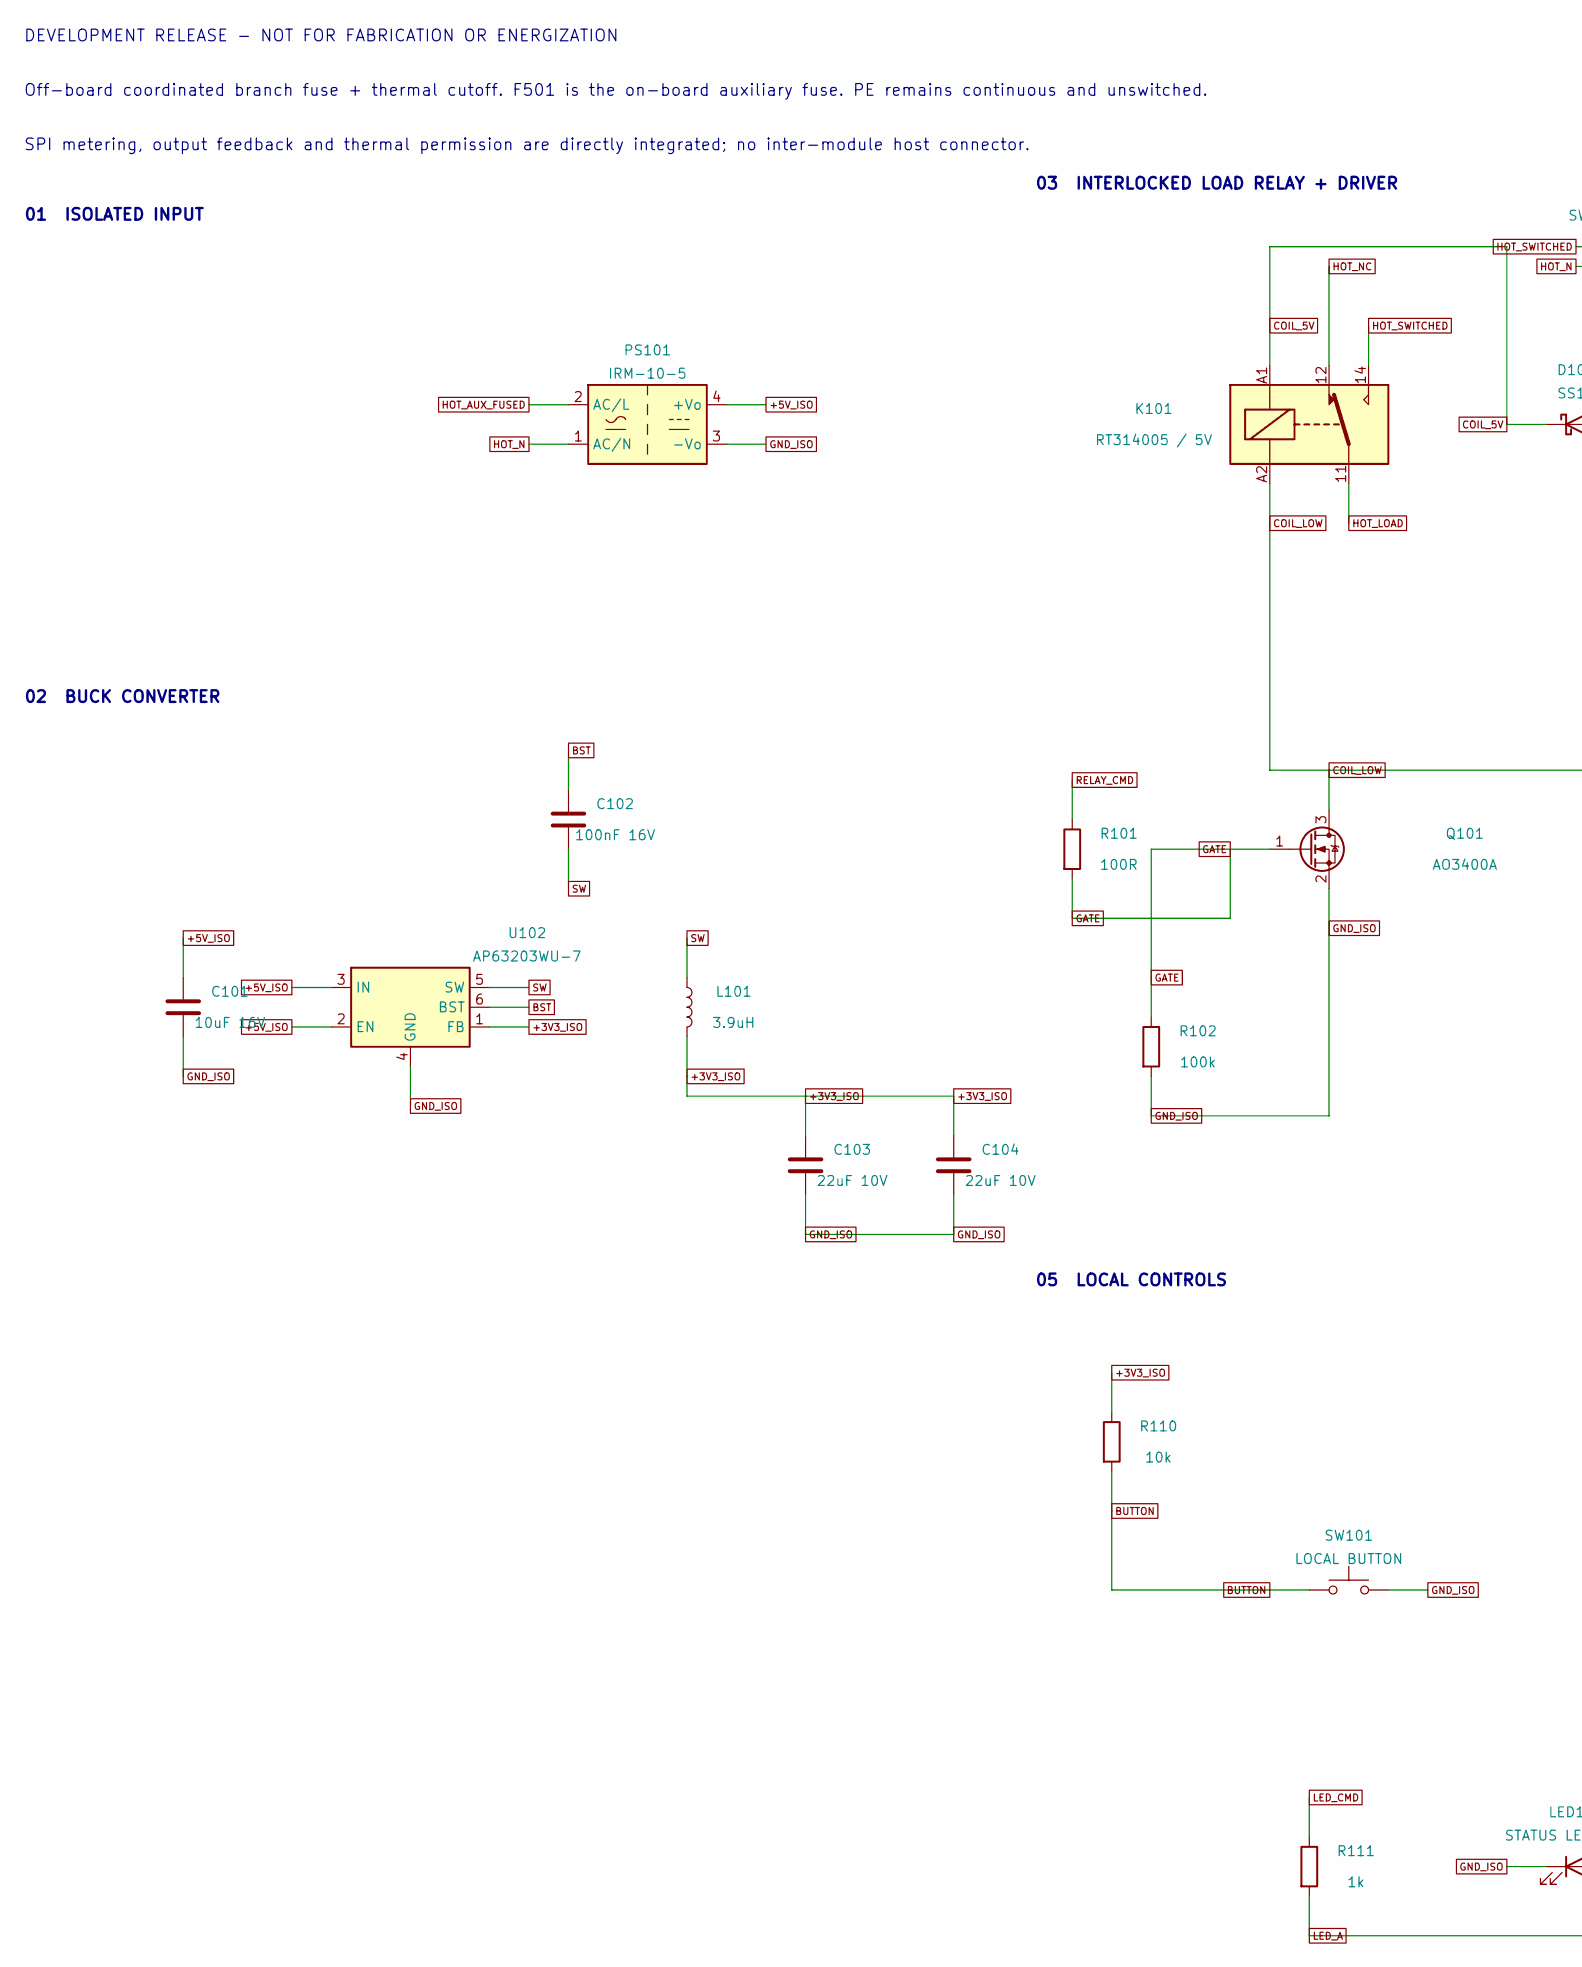
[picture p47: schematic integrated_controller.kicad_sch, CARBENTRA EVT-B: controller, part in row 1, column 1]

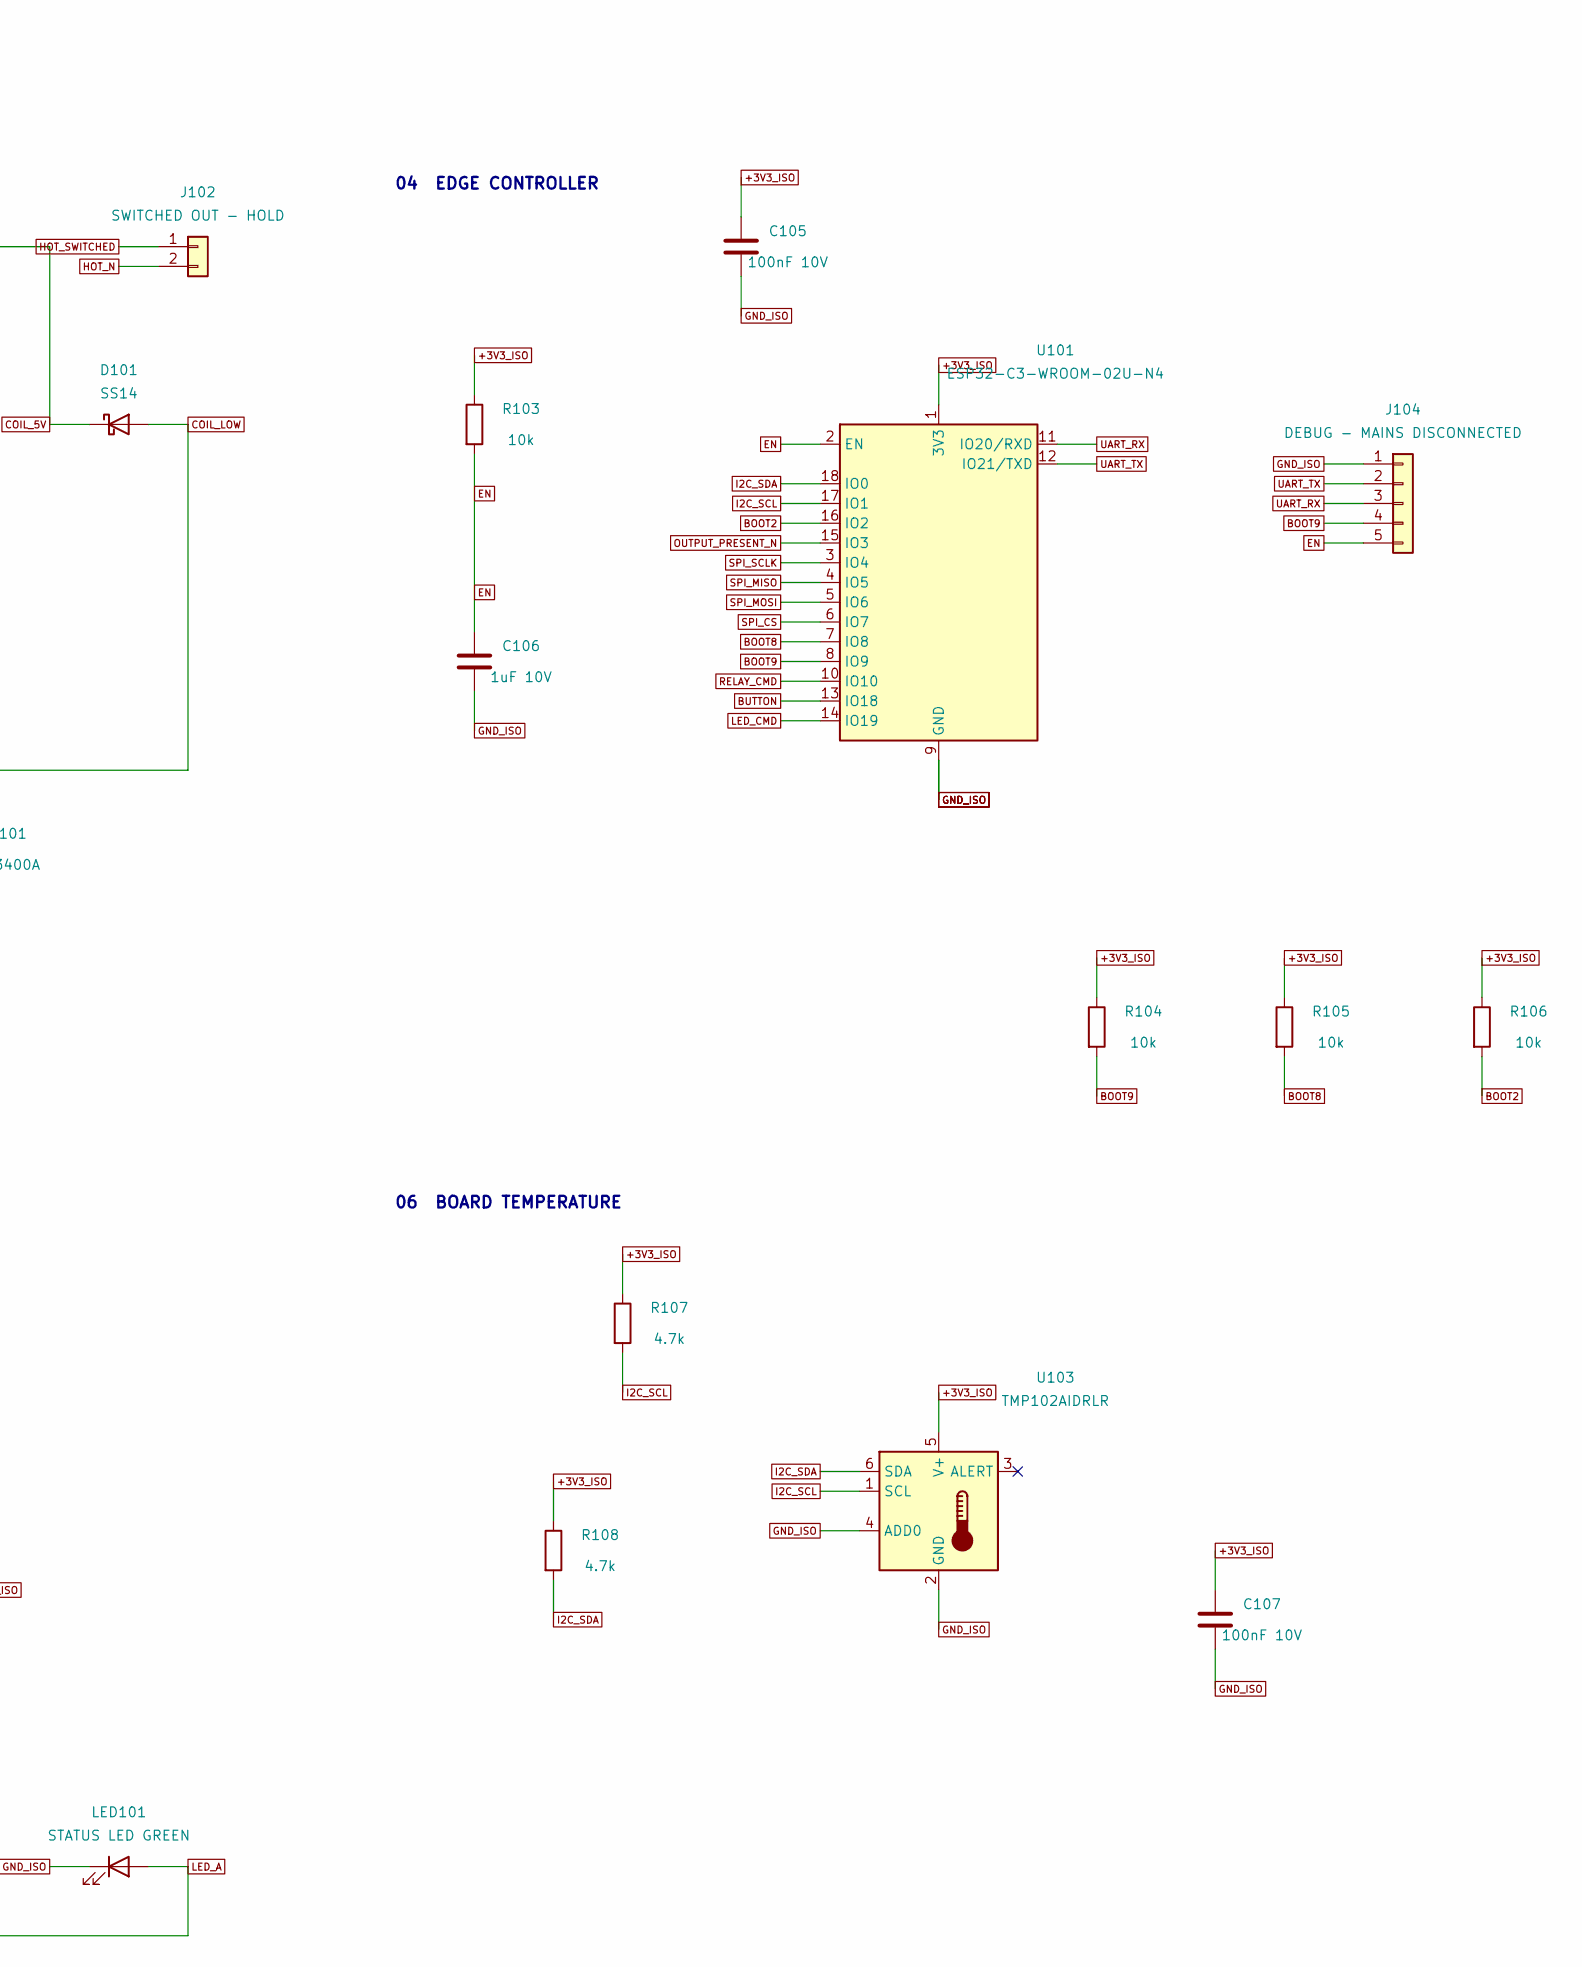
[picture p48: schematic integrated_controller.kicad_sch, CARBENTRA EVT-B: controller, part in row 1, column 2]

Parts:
C101: 10uF 16V; C_0805_2012Metric
C102: 100nF 16V; C_0805_2012Metric
C103, C104: 22uF 10V; C_0805_2012Metric
C105, C107: 100nF 10V; C_0805_2012Metric
C106: 1uF 10V; C_0805_2012Metric
D101: SS14; D_SMA
J102: SWITCHED OUT - HOLD; MKDS5_2_7p62
J104: DEBUG - MAINS DISCONNECTED; PinHeader_1x05_P2.54mm_Vertical
K101: RT314005 / 5V; Relay_SPDT_Schrack-RT1-16A-FormC_RM5mm
L101: 3.9uH; L_Bourns-SRN4018
LED101: STATUS LED GREEN; LED_D3.0mm
PS101: IRM-10-5; IRM10_Controller_Candidate
Q101: AO3400A; SOT-23
R101: 100R; R_0603_1608Metric
R102: 100k; R_0603_1608Metric
R103, R104, R105, R106, R110: 10k; R_0603_1608Metric
R107, R108: 4.7k; R_0603_1608Metric
R111: 1k; R_0603_1608Metric
SW101: LOCAL BUTTON; SW_PUSH_6mm
U101: ESP32-C3-WROOM-02U-N4; ESP32-C3-WROOM-02U
U102: AP63203WU-7; TSOT-23-6
U103: TMP102AIDRLR; SOT-563

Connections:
+3V3_ISO: C103.1, C104.1, C105.1, C107.1, L101.2, R103.1, R104.1, R105.1, R106.1, R107.1, R108.1, R110.1, U101.1 (3V3), U102.1 (FB), U103.5 (V+); also elsewhere on the board
+5V_ISO: C101.1, PS101.4 (+Vo), U102.2 (EN), U102.3 (IN); also elsewhere on the board
BOOT2: R106.2, U101.16 (IO2)
BOOT8: R105.2, U101.7 (IO8)
BOOT9: J104.4, R104.2, U101.8 (IO9)
BST: C102.1, U102.6 (BST)
BUTTON: R110.2, SW101.1, U101.13 (IO18)
COIL_5V: D101.1 (K), K101.A1; also elsewhere on the board
COIL_LOW: D101.2 (A), K101.A2, Q101.3 (D)
EN: C106.1, J104.5, R103.2, U101.2 (EN)
GATE: Q101.1 (G), R101.2, R102.1
GND_ISO: C101.2, C103.2, C104.2, C105.2, C106.2, C107.2, J104.1, LED101.1 (K), PS101.3 (-Vo), Q101.2 (S), R102.2, SW101.2, U101.9 (GND), U101.19 (GND), U102.4 (GND), U103.2 (GND), U103.4 (ADD0); also elsewhere on the board
HOT_AUX_FUSED: PS101.2 (AC/L); also elsewhere on the board
HOT_LOAD: K101.11; also elsewhere on the board
HOT_N: J102.2, PS101.1 (AC/N); also elsewhere on the board
HOT_NC: K101.12
HOT_SWITCHED: J102.1, K101.14; also elsewhere on the board
I2C_SCL: R107.2, U101.17 (IO1), U103.1 (SCL)
I2C_SDA: R108.2, U101.18 (IO0), U103.6 (SDA)
LED_A: LED101.2 (A), R111.2
LED_CMD: R111.1, U101.14 (IO19)
OUTPUT_PRESENT_N: U101.15 (IO3); also elsewhere on the board
RELAY_CMD: R101.1, U101.10 (IO10)
SPI_CS: U101.6 (IO7); also elsewhere on the board
SPI_MISO: U101.4 (IO5); also elsewhere on the board
SPI_MOSI: U101.5 (IO6); also elsewhere on the board
SPI_SCLK: U101.3 (IO4); also elsewhere on the board
SW: C102.2, L101.1, U102.5 (SW)
UART_RX: J104.3, U101.11 (IO20/RXD)
UART_TX: J104.2, U101.12 (IO21/TXD)

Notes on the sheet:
DEVELOPMENT RELEASE - NOT FOR FABRICATION OR ENERGIZATION
Off-board coordinated branch fuse + thermal cutoff. F501 is the on-board auxiliary fuse. PE remains continuous and unswitched.
SPI metering, output feedback and thermal permission are directly integrated; no inter-module host connector.
01 ISOLATED INPUT
02 BUCK CONVERTER
03 INTERLOCKED LOAD RELAY + DRIVER
04 EDGE CONTROLLER
05 LOCAL CONTROLS
06 BOARD TEMPERATURE

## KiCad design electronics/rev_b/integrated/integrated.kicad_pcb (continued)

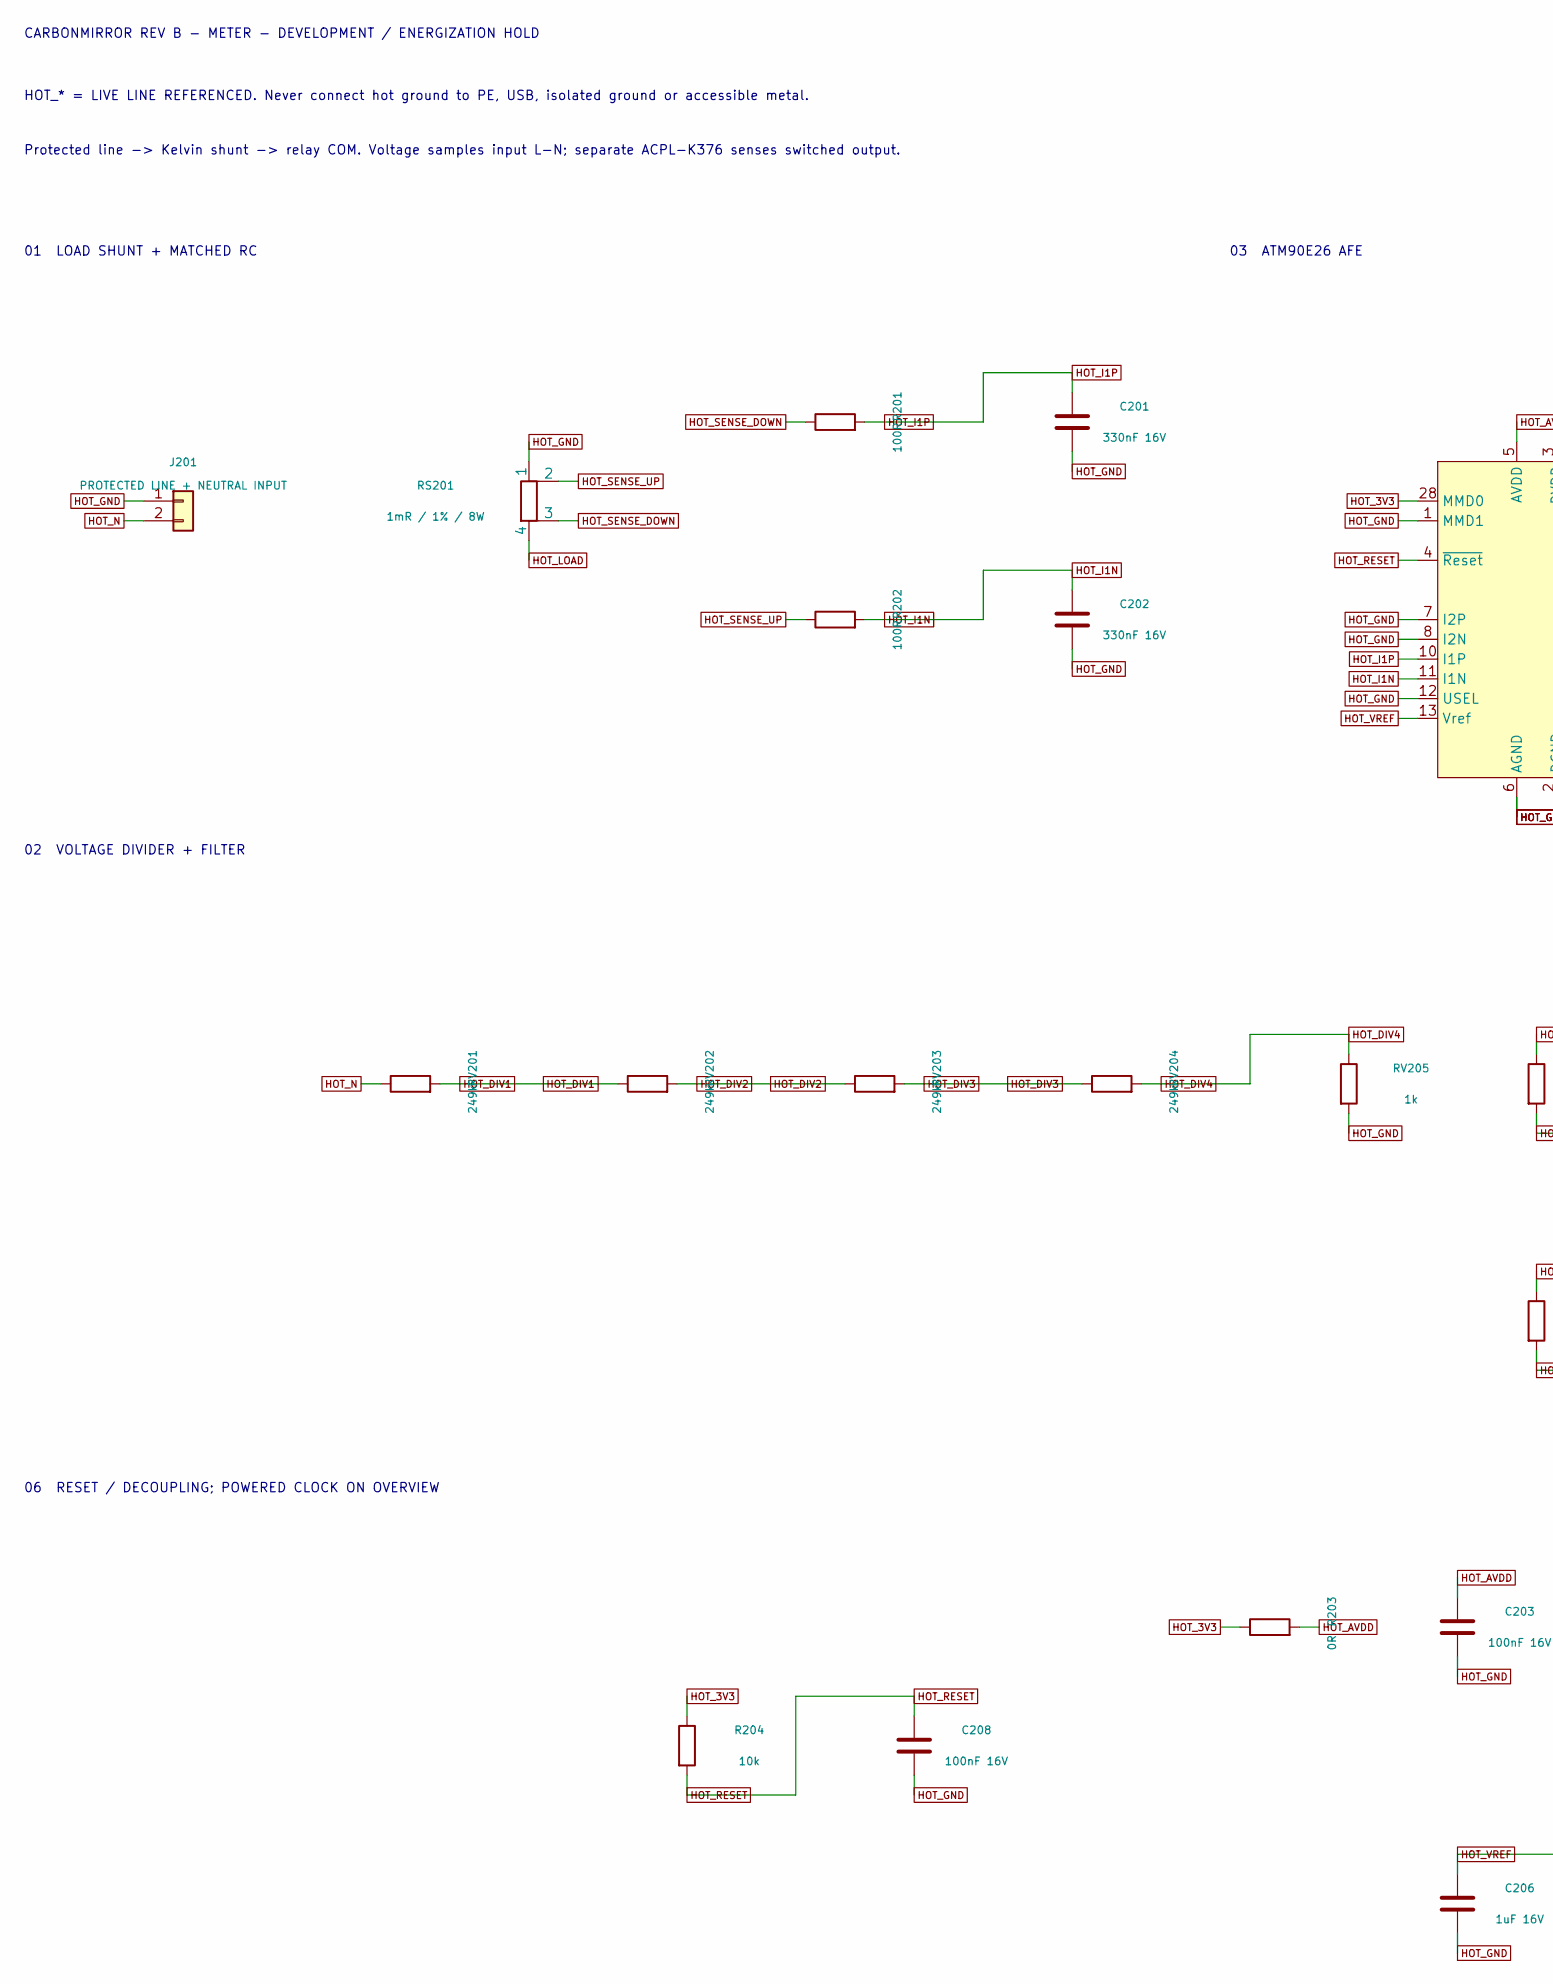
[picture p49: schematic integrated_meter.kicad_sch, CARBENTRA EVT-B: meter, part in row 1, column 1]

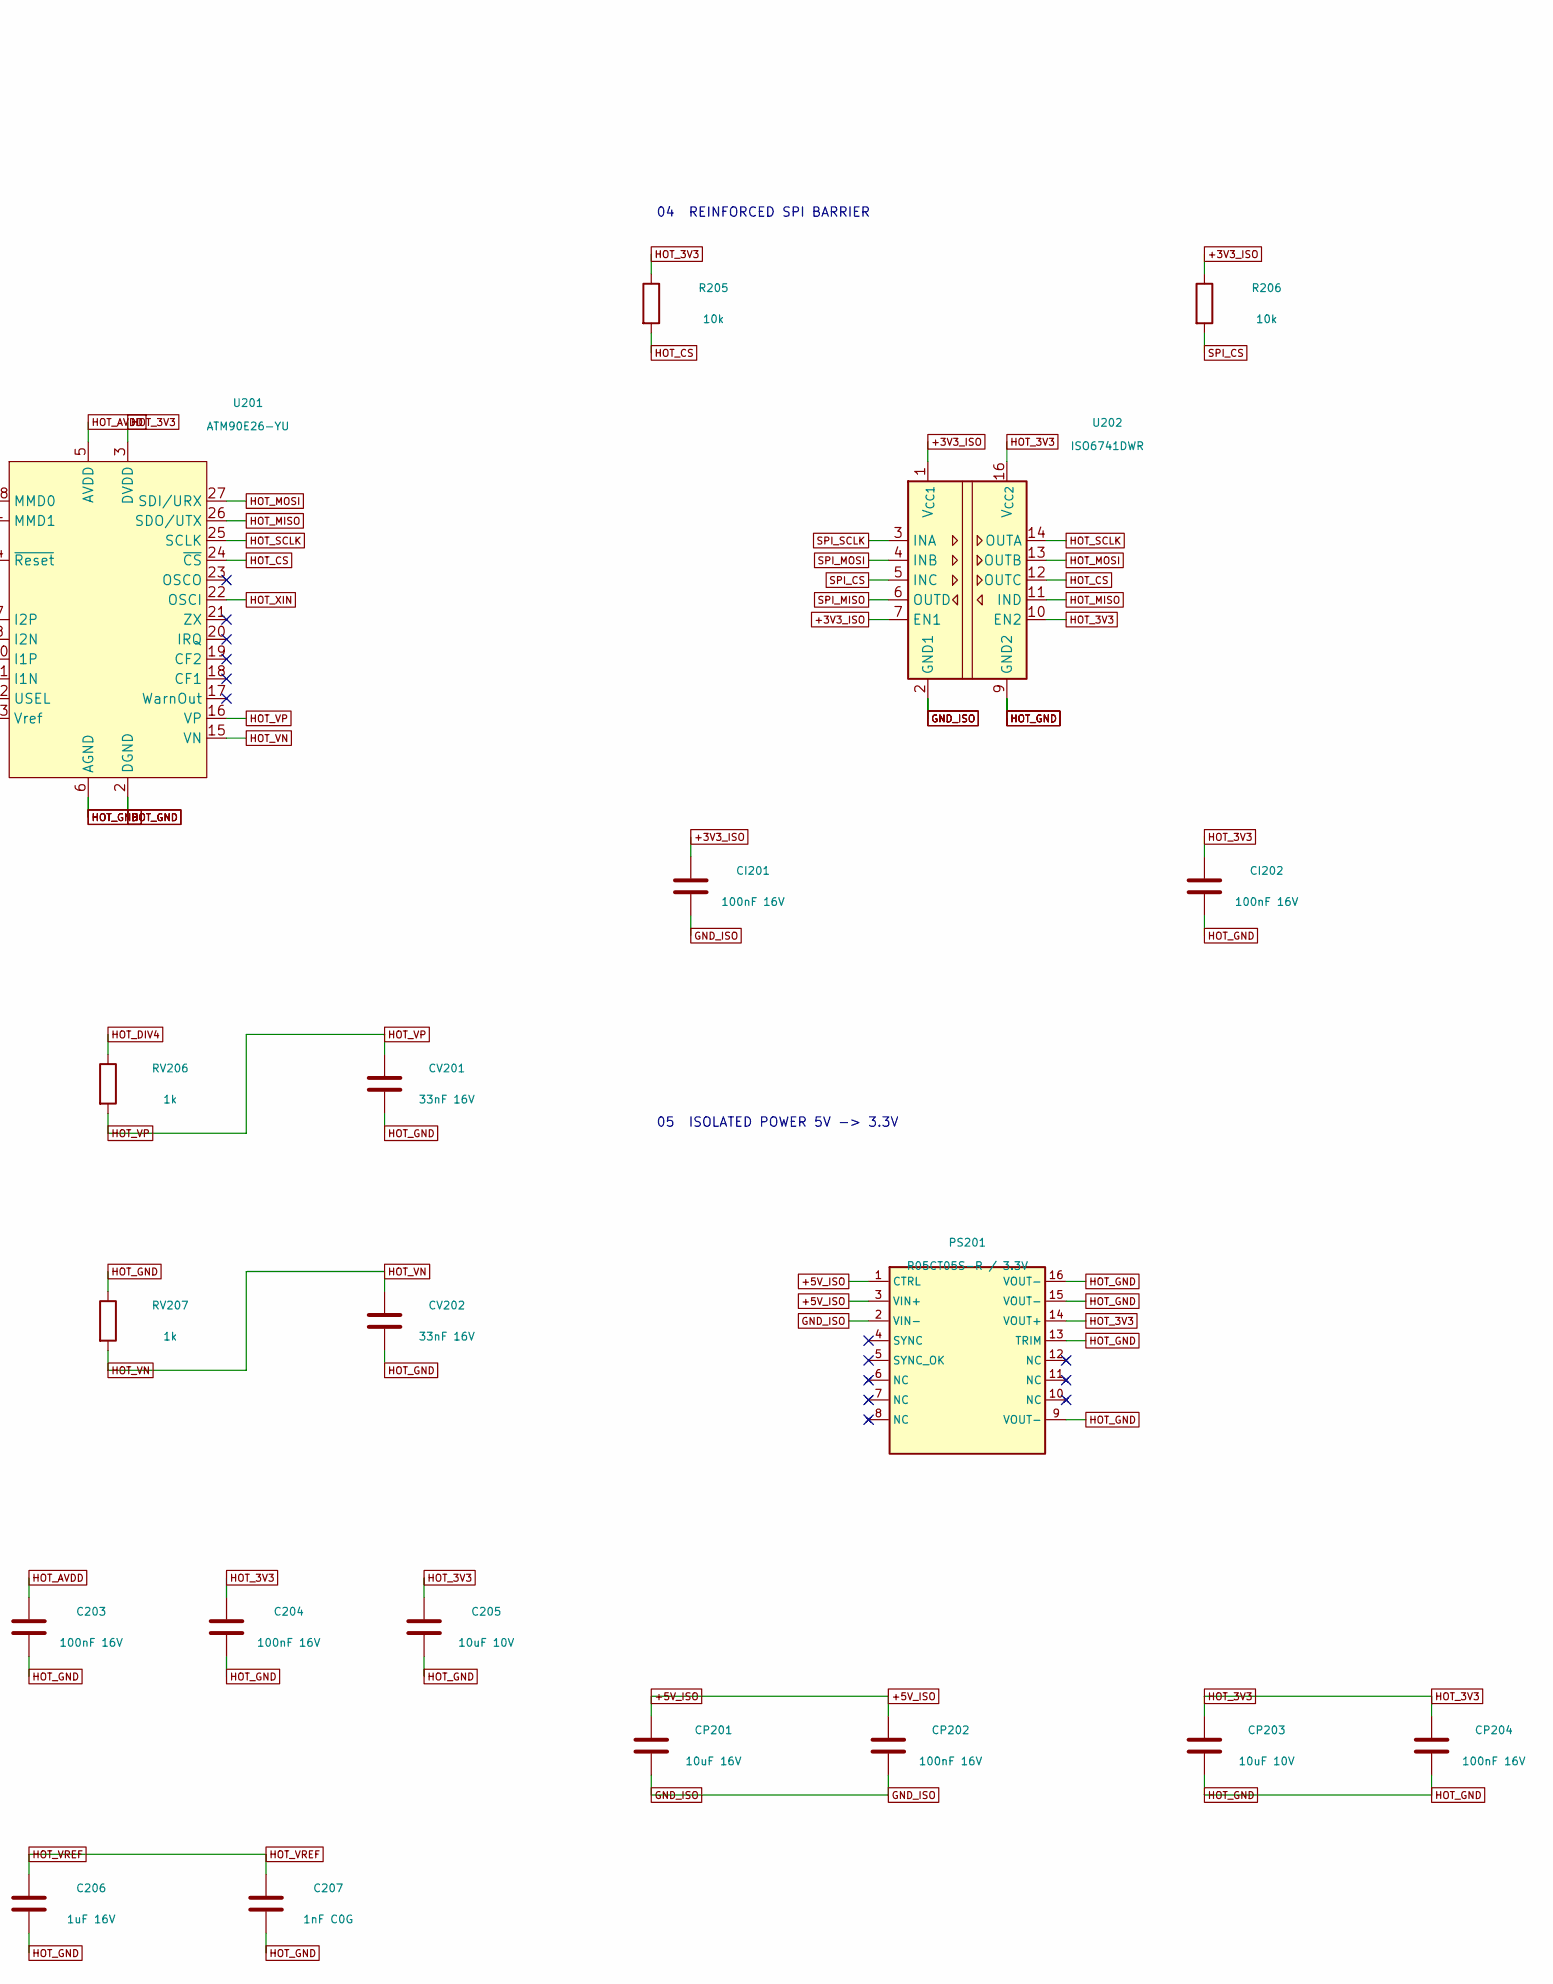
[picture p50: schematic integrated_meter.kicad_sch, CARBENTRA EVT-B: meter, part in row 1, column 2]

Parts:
C201, C202: 330nF 16V; C_0805_2012Metric
C203, C204, C208: 100nF 16V; C_0805_2012Metric
C205: 10uF 10V; C_0805_2012Metric
C206: 1uF 16V; C_0805_2012Metric
C207: 1nF C0G; C_0805_2012Metric
CI201, CI202: 100nF 16V; C_0805_2012Metric
CP201: 10uF 16V; C_0805_2012Metric
CP202, CP204: 100nF 16V; C_0805_2012Metric
CP203: 10uF 10V; C_0805_2012Metric
CV201, CV202: 33nF 16V; C_0805_2012Metric
J201: PROTECTED LINE + NEUTRAL INPUT; MKDS5_2_7p62
PS201: R05CT05S-R / 3.3V; R05CT05S_8p1
R201, R202: 100R; R_0603_1608Metric
R203: 0R; R_0805_2012Metric
R204, R205, R206: 10k; R_0805_2012Metric
RS201: 1mR / 1% / 8W; CSS4J_4026
RV201, RV202, RV203, RV204: 249k; R_1206_3216Metric
RV205, RV206, RV207: 1k; R_0805_2012Metric
U201: ATM90E26-YU; SSOP-28_5.3x10.2mm_P0.65mm
U202: ISO6741DWR; ISO6741_DW_8p1

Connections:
+3V3_ISO: CI201.1, R206.1, U202.1 (V_{CC1}), U202.7 (EN1); also elsewhere on the board
+5V_ISO: CP201.1, CP202.1, PS201.1 (CTRL), PS201.3 (VIN+); also elsewhere on the board
GND_ISO: CI201.2, CP201.2, CP202.2, PS201.2 (VIN-), U202.2 (GND1), U202.8 (GND1); also elsewhere on the board
HOT_3V3: C204.1, C205.1, CI202.1, CP203.1, CP204.1, PS201.14 (VOUT+), R203.1, R204.1, R205.1, U201.3 (DVDD), U201.28 (MMD0), U202.10 (EN2), U202.16 (V_{CC2}); also elsewhere on the board
HOT_AVDD: C203.1, R203.2, U201.5 (AVDD)
HOT_CS: R205.2, U201.24 (~CS), U202.12 (OUTC)
HOT_DIV1: RV201.2, RV202.1
HOT_DIV2: RV202.2, RV203.1
HOT_DIV3: RV203.2, RV204.1
HOT_DIV4: RV204.2, RV205.1, RV206.1
HOT_GND: C201.2, C202.2, C203.2, C204.2, C205.2, C206.2, C207.2, C208.2, CI202.2, CP203.2, CP204.2, CV201.2, CV202.2, J201.1, PS201.9 (VOUT-), PS201.13 (TRIM), PS201.15 (VOUT-), PS201.16 (VOUT-), RS201.1, RV205.2, RV207.1, U201.1 (MMD1), U201.2 (DGND), U201.6 (AGND), U201.7 (I2P), U201.8 (I2N), U201.9 (DGND), U201.12 (USEL), U201.14 (AGND), U202.9 (GND2), U202.15 (GND2); also elsewhere on the board
HOT_I1N: C202.1, R202.2, U201.11 (I1N)
HOT_I1P: C201.1, R201.2, U201.10 (I1P)
HOT_LOAD: RS201.4; also elsewhere on the board
HOT_MISO: U201.26 (SDO/UTX), U202.11 (IND)
HOT_MOSI: U201.27 (SDI/URX), U202.13 (OUTB)
HOT_N: J201.2, RV201.1; also elsewhere on the board
HOT_RESET: C208.1, R204.2, U201.4 (~Reset)
HOT_SCLK: U201.25 (SCLK), U202.14 (OUTA)
HOT_SENSE_DOWN: R201.1, RS201.3
HOT_SENSE_UP: R202.1, RS201.2
HOT_VN: CV202.1, RV207.2, U201.15 (VN)
HOT_VP: CV201.1, RV206.2, U201.16 (VP)
HOT_VREF: C206.1, C207.1, U201.13 (Vref)
HOT_XIN: U201.22 (OSCI); also elsewhere on the board
SPI_CS: R206.2, U202.5 (INC); also elsewhere on the board
SPI_MISO: U202.6 (OUTD); also elsewhere on the board
SPI_MOSI: U202.4 (INB); also elsewhere on the board
SPI_SCLK: U202.3 (INA); also elsewhere on the board

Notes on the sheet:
CARBONMIRROR REV B - METER - DEVELOPMENT / ENERGIZATION HOLD
HOT_* = LIVE LINE REFERENCED. Never connect hot ground to PE, USB, isolated ground or accessible metal.
Protected line -> Kelvin shunt -> relay COM. Voltage samples input L-N; separate ACPL-K376 senses switched output.
01 LOAD SHUNT + MATCHED RC
02 VOLTAGE DIVIDER + FILTER
03 ATM90E26 AFE
04 REINFORCED SPI BARRIER
05 ISOLATED POWER 5V -> 3.3V
06 RESET / DECOUPLING; POWERED CLOCK ON OVERVIEW

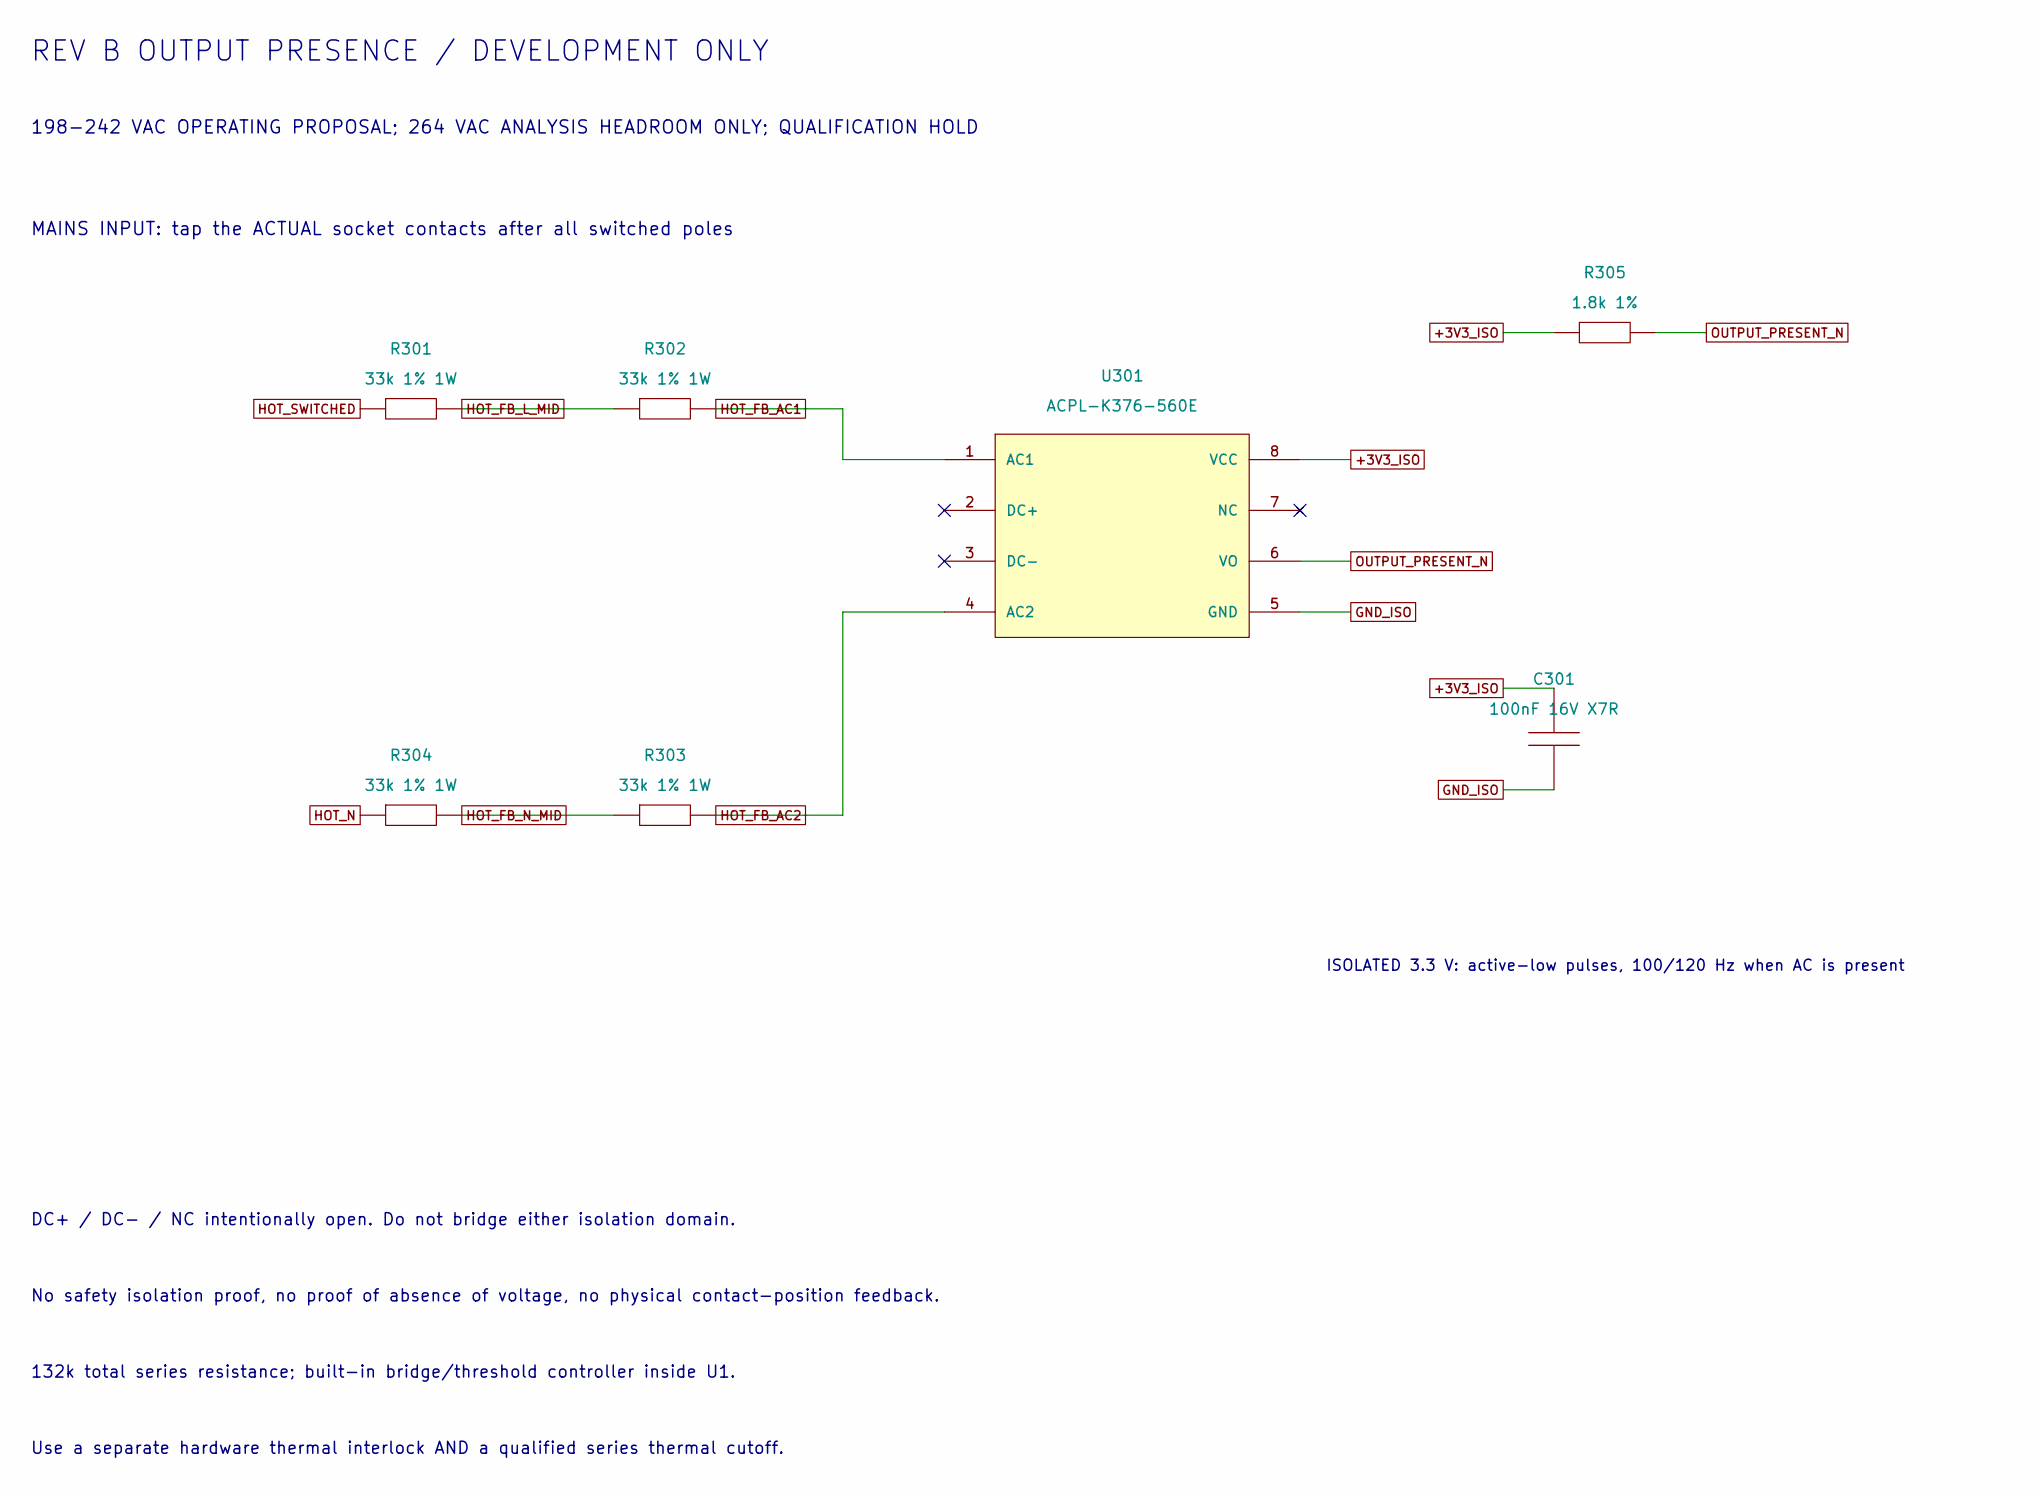
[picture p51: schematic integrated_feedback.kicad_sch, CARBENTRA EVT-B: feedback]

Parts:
C301: 100nF 16V X7R; C_0603_1608Metric
R301, R302, R303, R304: 33k 1% 1W; PR01_P10.16
R305: 1.8k 1%; R_0603_1608Metric
U301: ACPL-K376-560E; SSO8_ACPL_K376

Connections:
+3V3_ISO: C301.1, R305.1, U301.8 (VCC); also elsewhere on the board
GND_ISO: C301.2, U301.5 (GND); also elsewhere on the board
HOT_FB_AC1: R302.2, U301.1 (AC1)
HOT_FB_AC2: R303.2, U301.4 (AC2)
HOT_FB_L_MID: R301.2, R302.1
HOT_FB_N_MID: R303.1, R304.2
HOT_N: R304.1; also elsewhere on the board
HOT_SWITCHED: R301.1; also elsewhere on the board
OUTPUT_PRESENT_N: R305.2, U301.6 (VO); also elsewhere on the board

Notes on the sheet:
REV B OUTPUT PRESENCE / DEVELOPMENT ONLY
198-242 VAC OPERATING PROPOSAL; 264 VAC ANALYSIS HEADROOM ONLY; QUALIFICATION HOLD
MAINS INPUT: tap the ACTUAL socket contacts after all switched poles
ISOLATED 3.3 V: active-low pulses, 100/120 Hz when AC is present
DC+ / DC- / NC intentionally open. Do not bridge either isolation domain.
No safety isolation proof, no proof of absence of voltage, no physical contact-position feedback.
132k total series resistance; built-in bridge/threshold controller inside U1.
Use a separate hardware thermal interlock AND a qualified series thermal cutoff.

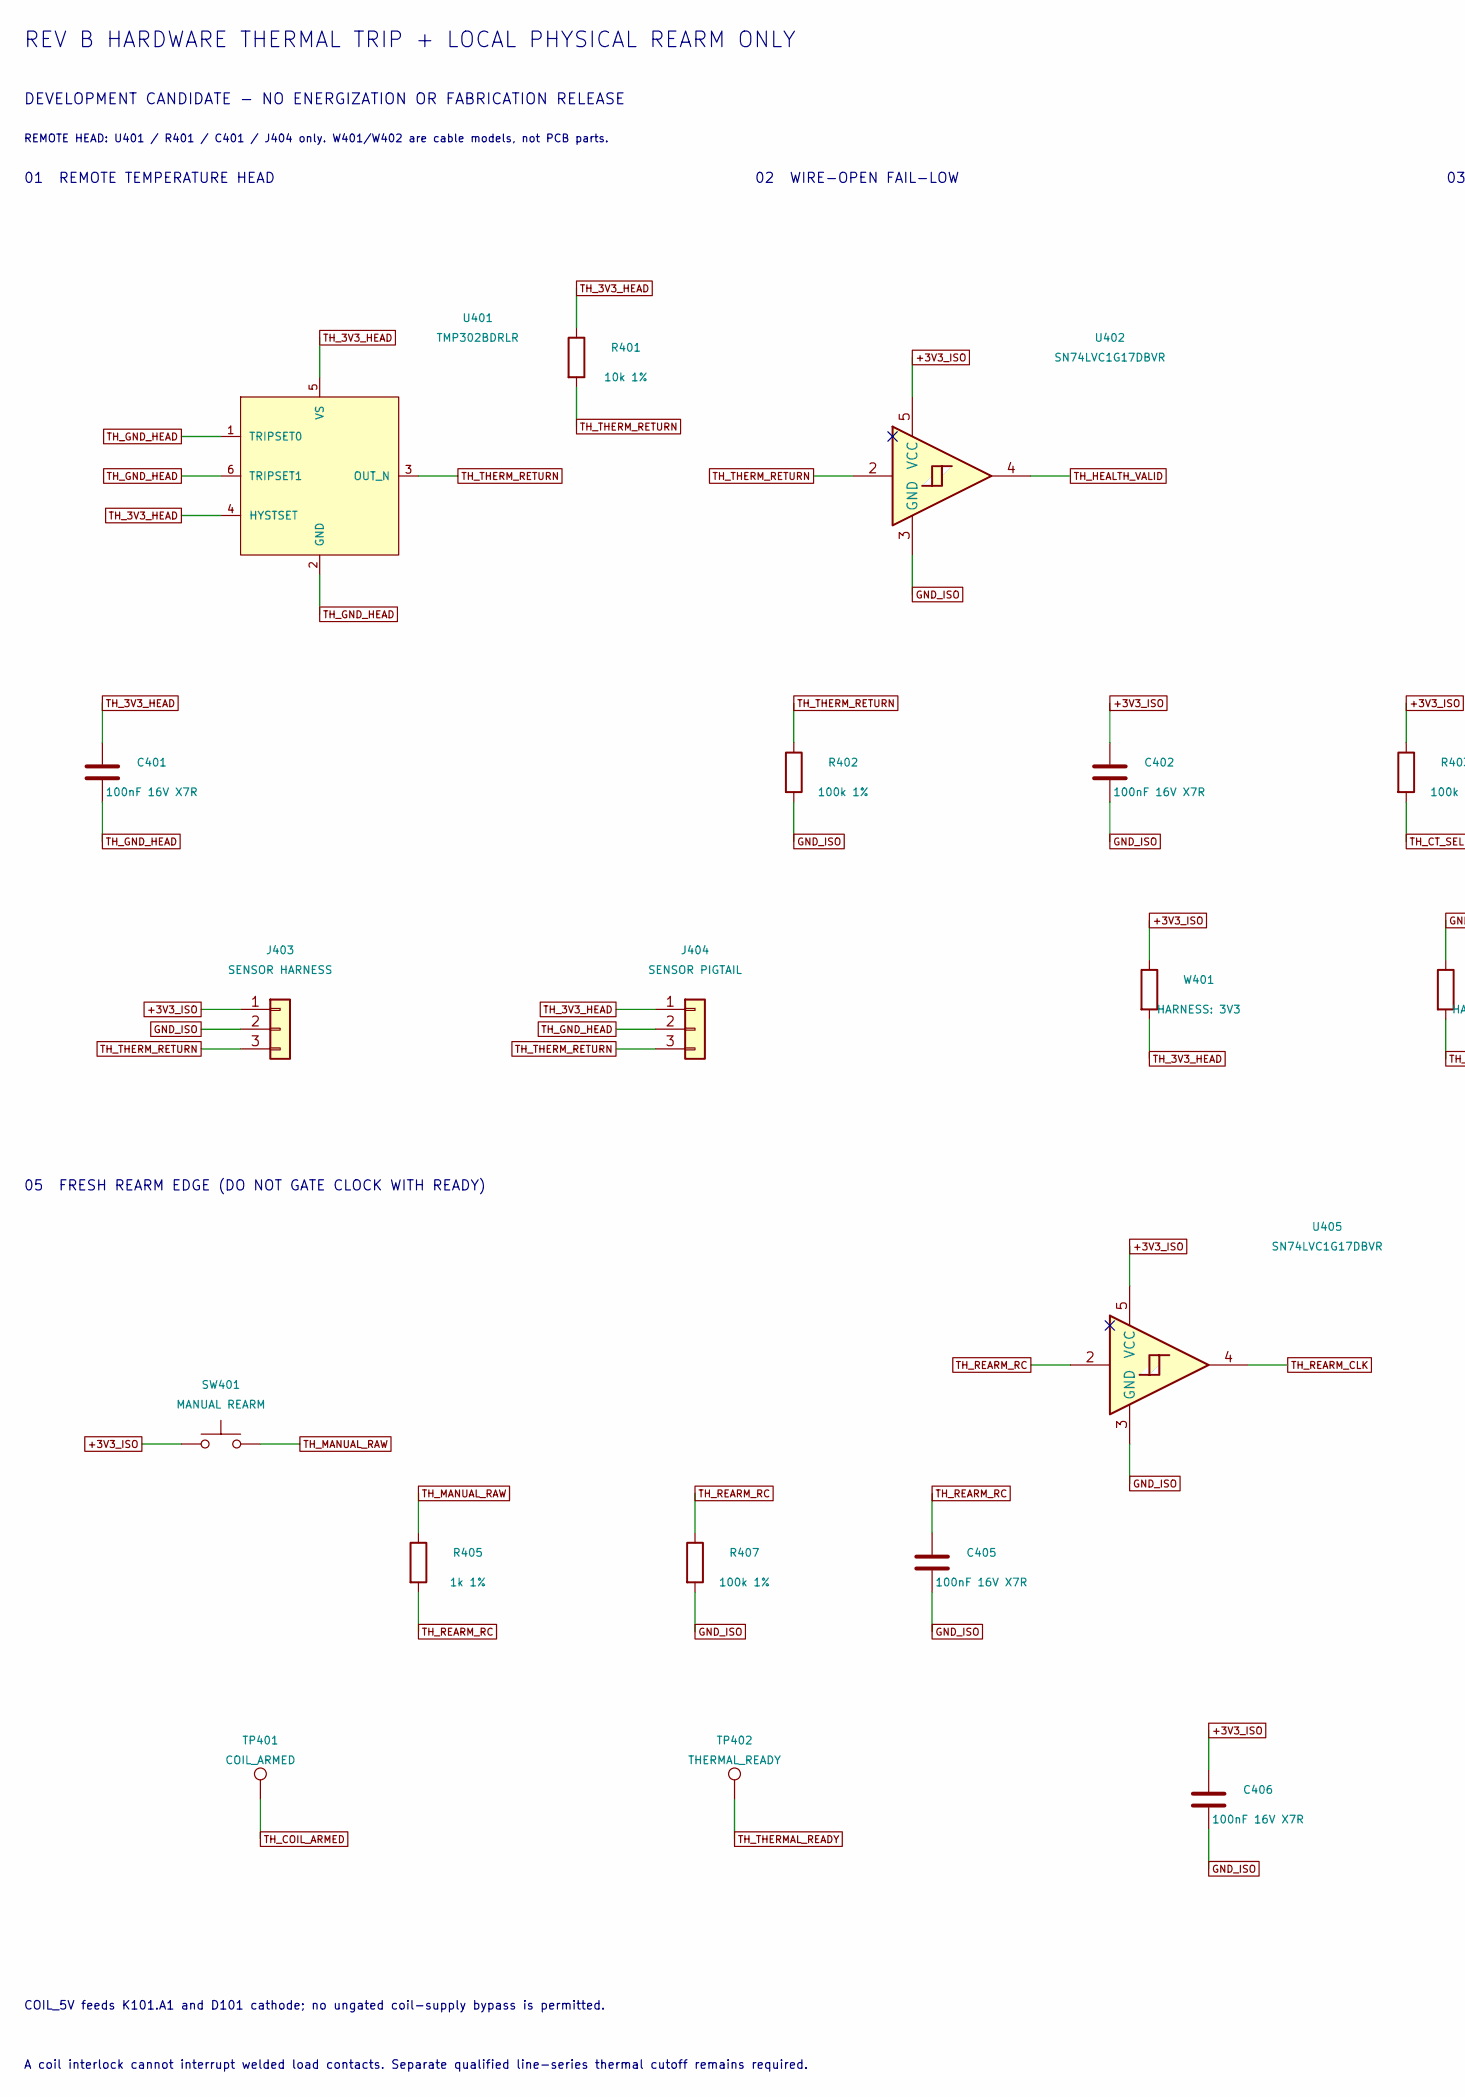
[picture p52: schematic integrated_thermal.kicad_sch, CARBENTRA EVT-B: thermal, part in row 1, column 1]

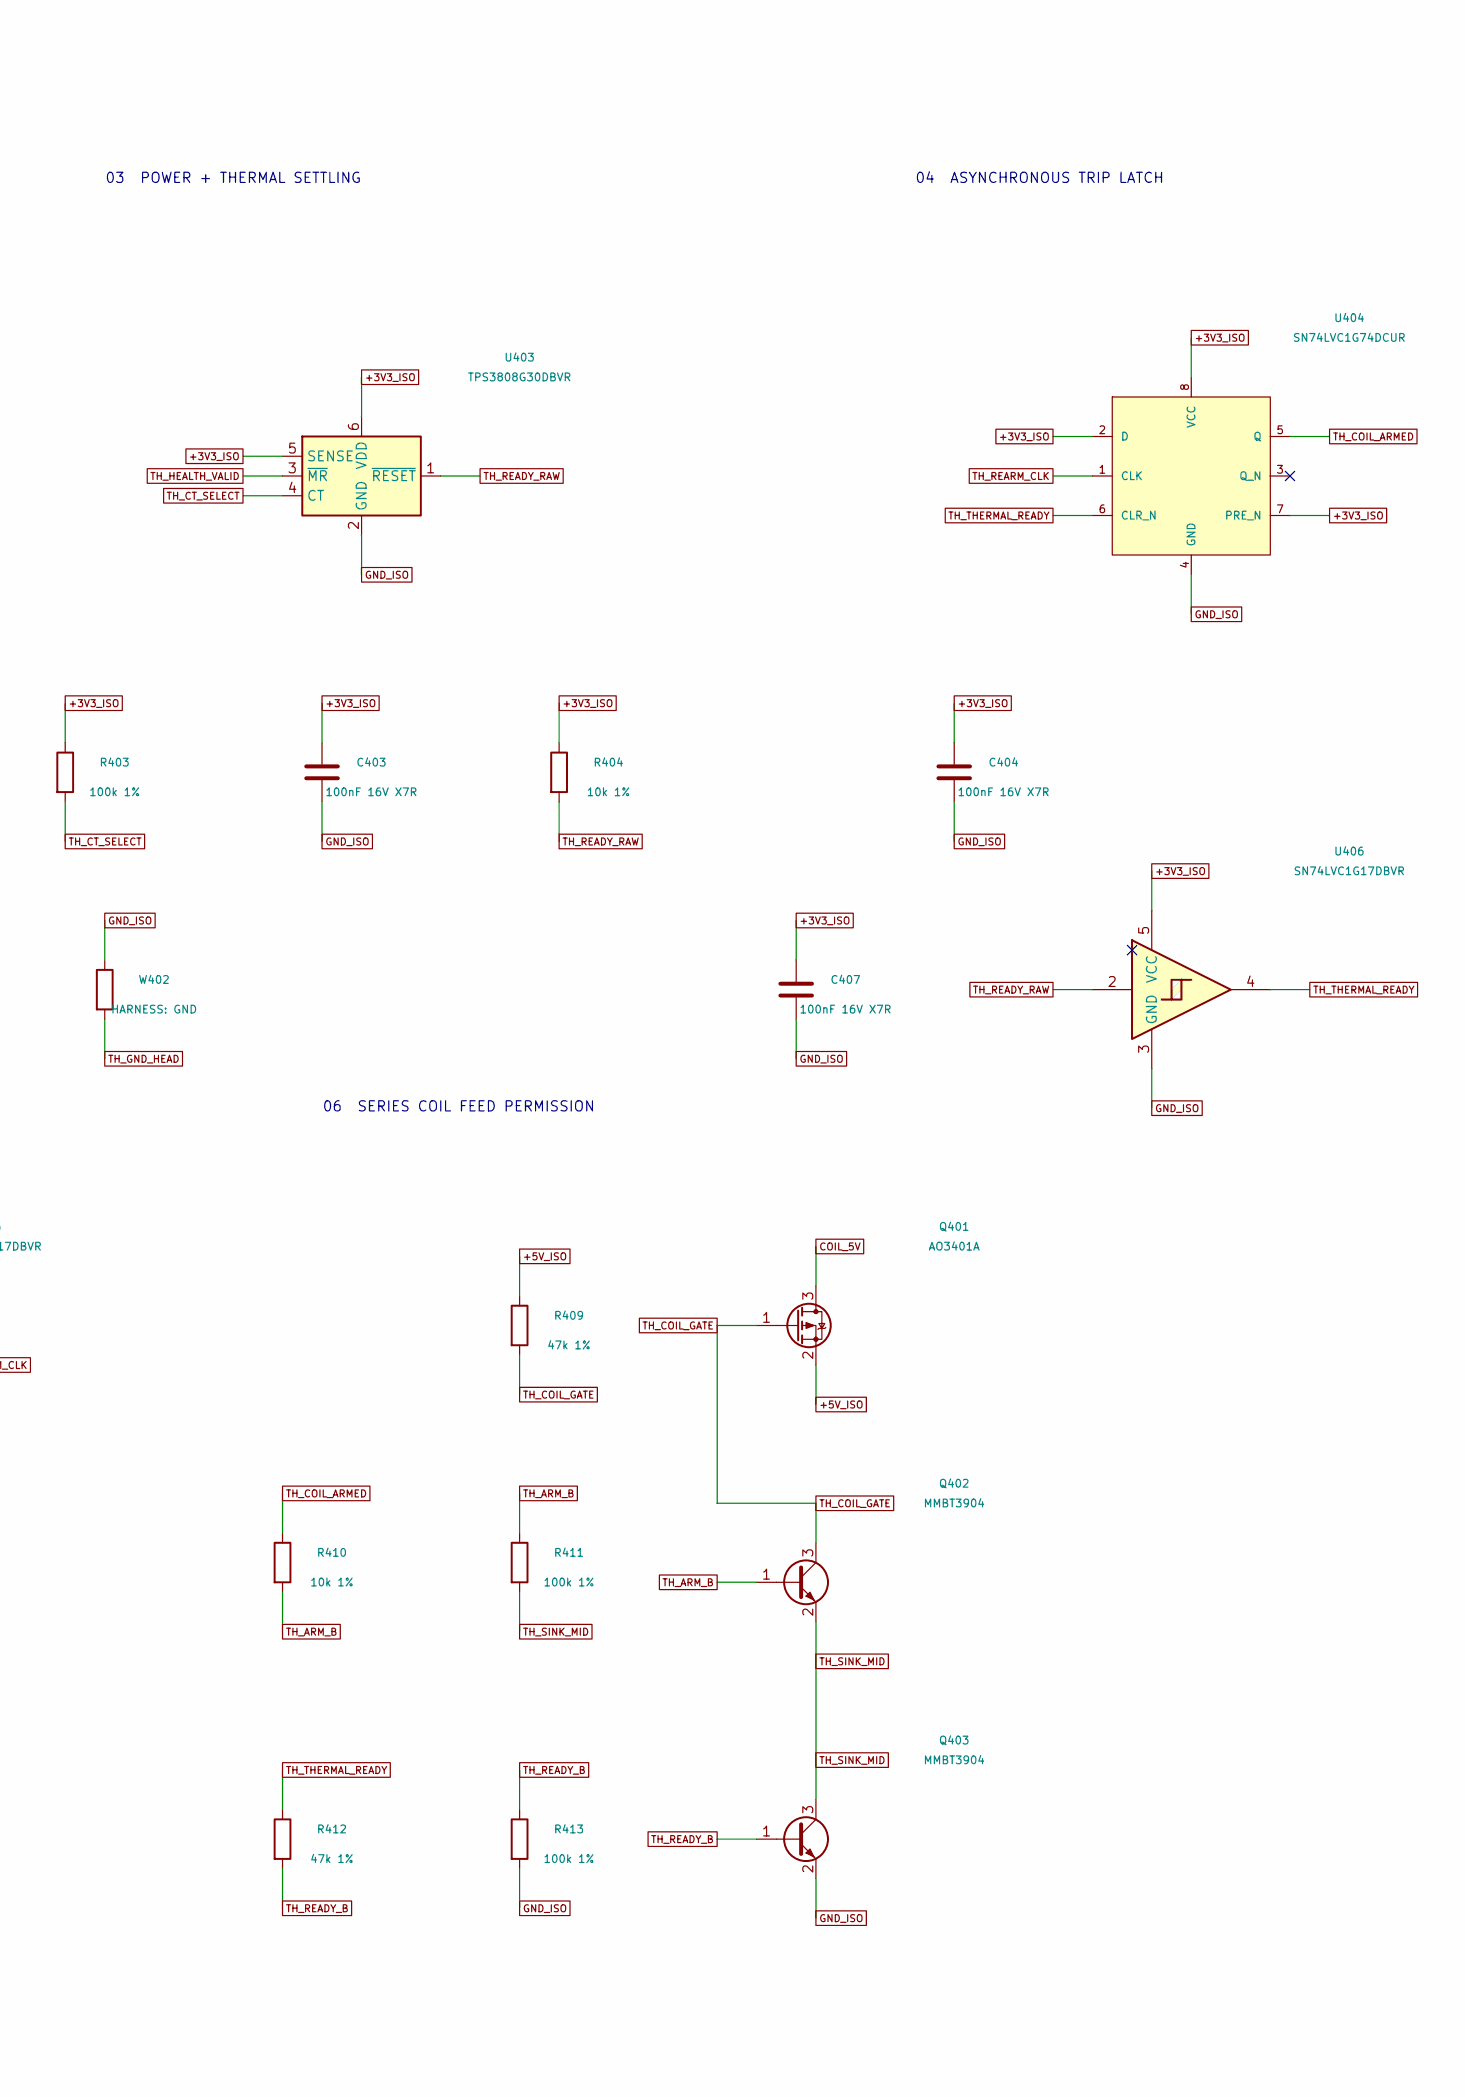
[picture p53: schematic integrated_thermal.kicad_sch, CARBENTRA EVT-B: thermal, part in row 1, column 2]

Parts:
C401, C402, C403, C404, C405, C406, C407: 100nF 16V X7R; C_0603_1608Metric
J403: SENSOR HARNESS; PinHeader_1x03_P2.54mm_Vertical
J404: SENSOR PIGTAIL; Sensor_Pigtail_3xP2.54
Q401: AO3401A; SOT-23
Q402, Q403: MMBT3904; SOT-23
R401, R404, R410: 10k 1%; R_0603_1608Metric
R402, R403, R407, R411, R413: 100k 1%; R_0603_1608Metric
R405: 1k 1%; R_0603_1608Metric
R409, R412: 47k 1%; R_0603_1608Metric
SW401: MANUAL REARM; SW_PUSH_6mm
TP401: COIL_ARMED; TestPoint_Pad_D1.0mm
TP402: THERMAL_READY; TestPoint_Pad_D1.0mm
U401: TMP302BDRLR; SOT-563
U402, U405, U406: SN74LVC1G17DBVR; SOT-23-5
U403: TPS3808G30DBVR; SOT-23-6
U404: SN74LVC1G74DCUR; VSSOP-8_2.3x2mm_P0.5mm
W401: HARNESS: 3V3; R_0603_1608Metric
W402: HARNESS: GND; R_0603_1608Metric

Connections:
+3V3_ISO: C402.1, C403.1, C404.1, C406.1, C407.1, J403.1, R403.1, R404.1, SW401.1, U402.5 (VCC), U403.5 (SENSE), U403.6 (VDD), U404.2 (D), U404.7 (PRE_N), U404.8 (VCC), U405.5 (VCC), U406.5 (VCC), W401.1; also elsewhere on the board
+5V_ISO: Q401.2 (S), R409.1; also elsewhere on the board
COIL_5V: Q401.3 (D); also elsewhere on the board
GND_ISO: C402.2, C403.2, C404.2, C405.2, C406.2, C407.2, J403.2, Q403.2 (E), R402.2, R407.2, R413.2, U402.3 (GND), U403.2 (GND), U404.4 (GND), U405.3 (GND), U406.3 (GND), W402.1; also elsewhere on the board
unnamed: C401.1, J404.1, R401.1, U401.4 (HYSTSET), U401.5 (VS), W401.2
unnamed: C401.2, J404.2, U401.1 (TRIPSET0), U401.2 (GND), U401.6 (TRIPSET1), W402.2
TH_ARM_B: Q402.1 (B), R410.2, R411.1
TH_COIL_ARMED: R410.1, TP401.1, U404.5 (Q)
TH_COIL_GATE: Q401.1 (G), Q402.3 (C), R409.2
TH_CT_SELECT: R403.2, U403.4 (CT)
TH_HEALTH_VALID: U402.4, U403.3 (~MR)
TH_MANUAL_RAW: R405.1, SW401.2
TH_READY_B: Q403.1 (B), R412.2, R413.1
TH_READY_RAW: R404.2, U403.1 (~RESET), U406.2
TH_REARM_CLK: U404.1 (CLK), U405.4
TH_REARM_RC: C405.1, R405.2, R407.1, U405.2
TH_SINK_MID: Q402.2 (E), Q403.3 (C), R411.2
TH_THERMAL_READY: R412.1, TP402.1, U404.6 (CLR_N), U406.4
TH_THERM_RETURN: J403.3, J404.3, R401.2, R402.1, U401.3 (OUT_N), U402.2

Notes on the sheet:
REV B HARDWARE THERMAL TRIP + LOCAL PHYSICAL REARM ONLY
DEVELOPMENT CANDIDATE - NO ENERGIZATION OR FABRICATION RELEASE
01 REMOTE TEMPERATURE HEAD
02 WIRE-OPEN FAIL-LOW
03 POWER + THERMAL SETTLING
04 ASYNCHRONOUS TRIP LATCH
05 FRESH REARM EDGE (DO NOT GATE CLOCK WITH READY)
06 SERIES COIL FEED PERMISSION
COIL_5V feeds K101.A1 and D101 cathode; no ungated coil-supply bypass is permitted.
A coil interlock cannot interrupt welded load contacts. Separate qualified line-series thermal cutoff remains required.
REMOTE HEAD: U401 / R401 / C401 / J404 only. W401/W402 are cable models, not PCB parts.

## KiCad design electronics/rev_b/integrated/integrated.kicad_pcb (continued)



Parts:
F601: 8020.5080 / 16A FAST
J601: CUSTOM PLUG / L N PE
J602: CUSTOM SOCKET / L N PE
TF601: G5 Tf110C / SUFFIX HOLD

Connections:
unnamed: F601.1 (IN), J601.1 (L)
unnamed: F601.2 (OUT), TF601.1 (CASE / IN)
unnamed: J601.2 (N), J602.2 (N)
unnamed: J601.3 (PE), J602.3 (PE)

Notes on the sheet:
R10 ASSEMBLY PROTECTION / OFF-BOARD INTERNAL PARTS
CANDIDATE ONLY: this sheet closes the drawn assembly path, not qualification or certification
MAIN PCB
J201.1 -> shunt + relay -> J102.1
J201.2 / J102.2 = HOT_N
PE: direct plug-to-socket path; NEVER through PCB, relay, fuse or software
F601 = MAIN 16 A fast-acting fuse. F501 = separate PCB auxiliary 1 A time-delay fuse.
TF601 = distinct one-shot MICROTEMP G5 thermal link, provisional Tf110C; order suffix and mounting HOLD.
SHF16A:1.5kA@250VAC cos(phi)0.7-0.8. Typical melting I2t760A2s is NOT total clearing or a downstream energy bound.
Upstream breaker, prospective fault current, fuse I2t/selectivity, hot-condition derating and wiring coordination are UNVERIFIED.
NO ACTIVE CURRENT LIMIT: a fuse rating is not a continuous-current clamp or a guaranteed socket overload threshold.
Custom contacts + 2x CQP8040.0003 clips;45x16x2 carrier / Cu collectors; fit accepted, heating/insulation HOLD.
Assembly contact numbers identify L/N/PE wiring. SHF8020.5080 fuse6.3x32mm replaces216/OGN for higher clip margin.
The main-PCB box references real circuits on sheets 1-4; it is not an electrical bypass between HOT_GND and HOT_SWITCHED.
PE continuity, polarity, touch protection, contact heating and cold-weld disconnection still require physical verification.
F601 / TF601 / J601 / J602 are on_board=false. Main PCB part count remains 101.


Board: 4 copper layers, 100.0 x 85.0 mm, 105 parts (1 on the bottom side), 66 nets.

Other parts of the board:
H1, H2, H3, H4: MountingHole_3.2mm_M3

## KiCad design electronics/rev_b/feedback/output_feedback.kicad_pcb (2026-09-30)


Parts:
C1: 100nF 16V X7R; C_0603_1608Metric
J1: POST-SWITCH L; Wire_Pad_1.2mm
J2: POST-SWITCH N; Wire_Pad_1.2mm
J3: 3V3 / GND / OUT_N; PinHeader_1x03_P2.54mm_Vertical
R1, R2, R3, R4: 33k 1% 1W; PR01_P10.16
R5: 1.8k 1%; R_0603_1608Metric
U1: ACPL-K376-560E; SSO8_ACPL_K376

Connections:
+3V3_ISO: C1.1, J3.1 (3V3), R5.1, U1.8 (VCC)
AC1: R2.2, U1.1 (AC1)
AC2: R3.2, U1.4 (AC2)
GND_ISO: C1.2, J3.2 (GND), U1.5 (GND)
L_MID: R1.2, R2.1
L_POST: J1.1, R1.1
N_MID: R3.1, R4.2
N_POST: J2.1, R4.1
OUTPUT_PRESENT_N: J3.3 (OUT_N), R5.2, U1.6 (VO)

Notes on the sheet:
REV B OUTPUT PRESENCE / DEVELOPMENT ONLY
198-264 VAC, 50/60 Hz | NO FABRICATION / NO ENERGIZATION RELEASE
MAINS INPUT: tap the ACTUAL socket contacts after all switched poles
ISOLATED 3.3 V: active-low pulses, 100/120 Hz when AC is present
DC+ / DC- / NC intentionally open. Do not bridge either isolation domain.
No safety isolation proof, no proof of absence of voltage, no physical contact-position feedback.
132k total series resistance; built-in bridge/threshold controller inside U1.
Use a separate hardware thermal interlock AND a qualified series thermal cutoff.


Board: 2 copper layers, 35.0 x 25.0 mm, 10 parts (0 on the bottom side), 9 nets.

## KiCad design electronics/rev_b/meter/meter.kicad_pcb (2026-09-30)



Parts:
C1, C2: 330nF 16V; C_0805_2012Metric
C3, C4, C8: 100nF 16V; C_0805_2012Metric
C5: 10uF 10V; C_0805_2012Metric
C6: 1uF 16V; C_0805_2012Metric
C7: 1nF C0G; C_0805_2012Metric
CI1, CI2: 100nF 16V; C_0805_2012Metric
CP1: 10uF 16V; C_0805_2012Metric
CP2, CP4: 100nF 16V; C_0805_2012Metric
CP3: 10uF 10V; C_0805_2012Metric
CV1, CV2: 33nF 16V; C_0805_2012Metric
CX1, CX2: 27pF C0G; C_0805_2012Metric
J1: PROTECTED L / TO RELAY; TerminalBlock_Phoenix_MKDS-3-2-5.08_1x02_P5.08mm_Horizontal
J2: N SENSE / NC; TerminalBlock_Phoenix_MKDS-3-2-5.08_1x02_P5.08mm_Horizontal
J3: CONTROLLER - ISOLATED; PinHeader_1x08_P2.54mm_Vertical
PS1: R05CT05S-R / 3.3V; R05CT05S_8p1
R1, R2: 100R; R_0805_2012Metric
R3: 0R; R_0805_2012Metric
R4, R5, R6: 10k; R_0805_2012Metric
RS1: 1mR / 1% / 8W; CSS4J_4026
RV1, RV2, RV3, RV4: 249k; R_1206_3216Metric
RV5, RV6, RV7: 1k; R_0805_2012Metric
U1: ATM90E26-YU; SSOP-28_5.3x10.2mm_P0.65mm
U2: ISO6741DWR; ISO6741_DW_8p1
Y1: 8.192MHz CL18pF; Crystal_SMD_HC49-SD

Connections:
HOT_3V3: C4.1, C5.1, CI2.1, CP3.1, CP4.1, PS1.14 (VOUT+), R3.1, R4.1, R5.1, U1.3 (DVDD), U1.28 (MMD0), U2.10 (EN2), U2.16 (V_{CC2})
HOT_AVDD: C3.1, R3.2, U1.5 (AVDD)
HOT_CS: R5.2, U1.24 (~CS), U2.12 (OUTC)
HOT_DIV1: RV1.2, RV2.1
HOT_DIV2: RV2.2, RV3.1
HOT_DIV3: RV3.2, RV4.1
HOT_DIV4: RV4.2, RV5.1, RV6.1
HOT_GND: C1.2, C2.2, C3.2, C4.2, C5.2, C6.2, C7.2, C8.2, CI2.2, CP3.2, CP4.2, CV1.2, CV2.2, CX1.2, CX2.2, J1.2, PS1.9 (VOUT-), PS1.13 (TRIM), PS1.15 (VOUT-), PS1.16 (VOUT-), RS1.1, RV5.2, RV7.1, U1.1 (MMD1), U1.2 (DGND), U1.6 (AGND), U1.7 (I2P), U1.8 (I2N), U1.9 (DGND), U1.12 (USEL), U1.14 (AGND), U2.9 (GND2), U2.15 (GND2)
HOT_I1N: C2.1, R2.2, U1.11 (I1N)
HOT_I1P: C1.1, R1.2, U1.10 (I1P)
HOT_LOAD: J1.1, RS1.4
HOT_MISO: U1.26 (SDO/UTX), U2.11 (IND)
HOT_MOSI: U1.27 (SDI/URX), U2.13 (OUTB)
HOT_N: J2.1, RV1.1
HOT_RESET: C8.1, R4.2, U1.4 (~Reset)
HOT_SCLK: U1.25 (SCLK), U2.14 (OUTA)
HOT_SENSE_DOWN: R1.1, RS1.3
HOT_SENSE_UP: R2.1, RS1.2
HOT_VN: CV2.1, RV7.2, U1.15 (VN)
HOT_VP: CV1.1, RV6.2, U1.16 (VP)
HOT_VREF: C6.1, C7.1, U1.13 (Vref)
HOT_XIN: CX1.1, U1.22 (OSCI), Y1.1
HOT_XOUT: CX2.1, U1.23 (OSCO), Y1.2
ISO_3V3: CI1.1, J3.1, R6.1, U2.1 (V_{CC1}), U2.7 (EN1)
ISO_5V: CP1.1, CP2.1, J3.7, PS1.1 (CTRL), PS1.3 (VIN+)
ISO_CS: J3.6, R6.2, U2.5 (INC)
ISO_GND: CI1.2, CP1.2, CP2.2, J3.2, J3.8, PS1.2 (VIN-), U2.2 (GND1), U2.8 (GND1)
ISO_MISO: J3.5, U2.6 (OUTD)
ISO_MOSI: J3.4, U2.4 (INB)
ISO_SCLK: J3.3, U2.3 (INA)

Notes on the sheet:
CARBONMIRROR REV B - METER - DEVELOPMENT / ENERGIZATION HOLD
HOT_* = LIVE LINE REFERENCED. Never connect hot ground to PE, USB, isolated ground or accessible metal.
Protected line -> Kelvin shunt -> relay COM. Voltage samples input L-N; separate ACPL-K376 senses switched output.
01 LOAD SHUNT + MATCHED RC
02 VOLTAGE DIVIDER + FILTER
03 ATM90E26 AFE
04 REINFORCED SPI BARRIER
05 ISOLATED POWER 5V -> 3.3V
06 CLOCK / RESET / DECOUPLING


Board: 2 copper layers, 75.0 x 45.0 mm, 43 parts (0 on the bottom side), 30 nets.

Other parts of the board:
H1, H2, H3, H4: MountingHole_2.2mm_M2

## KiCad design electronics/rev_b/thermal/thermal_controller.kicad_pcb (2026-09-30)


Board: 2 copper layers, 45.0 x 35.0 mm, 29 parts (0 on the bottom side), 17 nets.

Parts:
C2, C3, C4, C5, C6, C7: 100nF 16V X7R; C_0603_1608Metric
J1: MAIN 4-WIRE COIL INTERLOCK; PinHeader_1x04_P2.54mm_Vertical
J3: SENSOR HARNESS; PinHeader_1x03_P2.54mm_Vertical
Q1: AO3401A; SOT-23
Q2, Q3: MMBT3904; SOT-23
R2, R3, R7, R11, R13: 100k 1%; R_0603_1608Metric
R4, R10: 10k 1%; R_0603_1608Metric
R5: 1k 1%; R_0603_1608Metric
R9, R12: 47k 1%; R_0603_1608Metric
SW1: MANUAL REARM; SW_PUSH_6mm
TP1: COIL_ARMED; TestPoint_Pad_D1.0mm
TP2: THERMAL_READY; TestPoint_Pad_D1.0mm
U2, U5, U6: SN74LVC1G17DBVR; SOT-23-5
U3: TPS3808G30DBVR; SOT-23-6
U4: SN74LVC1G74DCUR; VSSOP-8_2.3x2mm_P0.5mm

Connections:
+3V3_ISO: C2.1, C3.1, C4.1, C6.1, C7.1, J1.2, J3.1, R3.1, R4.1, SW1.1, U2.5, U3.5, U3.6, U4.2, U4.7, U4.8, U5.5, U6.5
+5V_ISO: J1.1, Q1.2, R9.1
ARM_B: Q2.1, R10.2, R11.1
COIL_5V: J1.4, Q1.3
COIL_ARMED: R10.1, TP1.1, U4.5
COIL_GATE: Q1.1, Q2.3, R9.2
CT_SELECT: R3.2, U3.4
GND_ISO: C2.2, C3.2, C4.2, C5.2, C6.2, C7.2, J1.3, J3.2, Q3.2, R2.2, R7.2, R13.2, U2.3, U3.2, U4.4, U5.3, U6.3
HEALTH_VALID: U2.4, U3.3
MANUAL_RAW: R5.1, SW1.2
READY_B: Q3.1, R12.2, R13.1
READY_RAW: R4.2, U3.1, U6.2
REARM_CLK: U4.1, U5.4
REARM_RC: C5.1, R5.2, R7.1, U5.2
SINK_MID: Q2.2, Q3.3, R11.2
THERMAL_READY: R12.1, TP2.1, U4.6, U6.4
THERM_RETURN: J3.3, R2.1, U2.2

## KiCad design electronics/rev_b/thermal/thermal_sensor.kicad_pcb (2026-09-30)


Board: 2 copper layers, 12.0 x 12.0 mm, 4 parts (0 on the bottom side), 3 nets.

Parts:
C1: 100nF 16V X7R; C_0603_1608Metric
J4: SENSOR PIGTAIL; Sensor_Pigtail_3xP2.54
R1: 10k 1%; R_0603_1608Metric
U1: TMP302BDRLR; SOT-563

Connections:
+3V3_HEAD: C1.1, J4.1, R1.1, U1.4, U1.5
GND_HEAD: C1.2, J4.2, U1.1, U1.2, U1.6
THERM_RETURN: J4.3, R1.2, U1.3

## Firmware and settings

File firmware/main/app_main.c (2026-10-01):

#include <stdio.h>
#include <string.h>
#include <inttypes.h>
#include <time.h>
#include "freertos/FreeRTOS.h"
#include "freertos/task.h"
#include "driver/gpio.h"
#include "esp_timer.h"
#include "esp_log.h"
#include "esp_mac.h"
#include "nvs_flash.h"
#include "nvs.h"
#include "cJSON.h"
#include "carbentra_policy.h"
#include "carbentra_network.h"
#include "carbentra_meter.h"
#include "carbentra_meter_decode.h"
#include "carbentra_feedback.h"
#include "carbentra_storage.h"
#include "carbentra_storage_contract.h"
#include "carbentra_execution.h"
#if !CONFIG_CARBENTRA_BOARD_REV_B
#error "This firmware supports only the reviewed Rev B pin contract"
#endif
#define RELAY_GPIO 10
#define BUTTON_GPIO 18
#define LED_GPIO 19
#define FEEDBACK_GPIO 3
#define BUFFER_CAP 64
static carbentra_state state;
static carbentra_profile profile={.id="unknown",.min_on_ms=300000,.min_off_ms=300000};
static carbentra_measurement measurement;
static carbentra_feedback_state feedback_state;
static portMUX_TYPE feedback_mux=portMUX_INITIALIZER_UNLOCKED;
static const char*TAG="carbentra_endpoint";
static nvs_handle_t journal;
static bool journal_ready;
static uint64_t last_accepted_ms;
static carbentra_execution execution;
static unsigned dropped_telemetry;
static char boot_epoch[33];
static uint64_t last_sample_send_ms;
static carbentra_button local_button;
static uint64_t local_event_seq,local_event_ms;
static carbentra_result local_event_result=CARBENTRA_INVALID;
static double energy_forward_wh,energy_reverse_wh;static unsigned energy_gaps;
typedef struct {carbentra_measurement m;int64_t lower_s,upper_s;uint64_t monotonic_ms;bool time_trusted,fault_latched,desired_on,output_present,feedback_valid;uint64_t seq,local_event_seq,local_event_ms,manual_hold_until_ms;carbentra_result local_event_result;const char *control_mode;bool commissioned,maintenance;carbentra_feedback_status feedback_status;bool calibrated;double forward_wh,reverse_wh;unsigned energy_gaps,ram_dropped,command_dropped;} sample;
static sample buffer[BUFFER_CAP];static size_t head,count;static uint64_t sample_seq;
static void feedback_edge(void*arg){
 (void)arg;uint64_t now=esp_timer_get_time();bool level=gpio_get_level(FEEDBACK_GPIO);
 portENTER_CRITICAL_ISR(&feedback_mux);carbentra_feedback_edge(&feedback_state,now,level);portEXIT_CRITICAL_ISR(&feedback_mux);
}
static carbentra_feedback_status feedback_status(uint64_t unused_ms){
 (void)unused_ms;
 portENTER_CRITICAL(&feedback_mux);carbentra_feedback_state snapshot=feedback_state;portEXIT_CRITICAL(&feedback_mux);
 return carbentra_feedback_classify(&snapshot,esp_timer_get_time());
}
static bool request_relay(bool on){
 #if CONFIG_CARBENTRA_ALLOW_ACTUATION
 if(on&&!state.commissioned)return false;
 return gpio_set_level(RELAY_GPIO,on?1:0)==ESP_OK;
 #else
 gpio_set_level(RELAY_GPIO,0);return !on;
 #endif
}
static bool save_sequence(uint64_t seq){return journal_ready&&nvs_set_u64(journal,"last_seq",seq)==ESP_OK&&nvs_commit(journal)==ESP_OK;}
static bool acknowledge(const carbentra_command*c,const char*status,const carbentra_execution*result){
 if(!carbentra_network_online())return false;
 cJSON*j=cJSON_CreateObject();if(!j)return false;char seq[24];snprintf(seq,sizeof(seq),"%"PRIu64,c->seq);
 cJSON_AddNumberToObject(j,"schema_version",CARBENTRA_WIRE_VERSION);
 cJSON_AddStringToObject(j,"device_id",state.device_id);cJSON_AddStringToObject(j,"boot_epoch",boot_epoch);
 cJSON_AddStringToObject(j,"id",c->id);cJSON_AddStringToObject(j,"seq",seq);cJSON_AddStringToObject(j,"status",status);
 bool terminal=result?result->status!=CARBENTRA_EXEC_WAITING:true;
 cJSON_AddBoolToObject(j,"terminal",terminal);
 cJSON_AddBoolToObject(j,"desired_on",result&&terminal?result->desired_on:state.desired_on);
 cJSON_AddBoolToObject(j,"fault_latched",result&&terminal?result->fault_latched:state.fault_latched);
 cJSON_AddBoolToObject(j,"voltage_absence_proven",false);
 if(result){
  cJSON_AddNumberToObject(j,"requested_monotonic_ms",(double)result->requested_ms);
  cJSON_AddNumberToObject(j,"deadline_monotonic_ms",(double)result->deadline_ms);
  if(terminal){
   cJSON_AddNumberToObject(j,"observed_monotonic_ms",(double)result->observed_ms);
   cJSON_AddBoolToObject(j,"feedback_valid",result->feedback_valid);cJSON_AddBoolToObject(j,"output_present",result->output_present);
   cJSON_AddStringToObject(j,"output_sensing",carbentra_feedback_name(result->sensing));
  }
 }
 char*text=cJSON_PrintUnformatted(j);bool ok=text&&carbentra_network_publish("ack",text)>=0;
 if(text){cJSON_free(text);}
 cJSON_Delete(j);return ok;
}
static void load_profile(void){nvs_handle_t n;if(nvs_open(CARBENTRA_NVS_FACTORY,NVS_READONLY,&n)!=ESP_OK)return;
 size_t len=sizeof(profile.id);uint8_t approved=0,critical=1,shed=0,commissioned=0;
 if(nvs_get_str(n,"profile_id",profile.id,&len)!=ESP_OK)strcpy(profile.id,"unknown");
 uint8_t maintenance=0;esp_err_t maintenance_status=nvs_get_u8(n,"maintenance",&maintenance);state.maintenance=maintenance!=0||(maintenance_status!=ESP_OK&&maintenance_status!=ESP_ERR_NVS_NOT_FOUND);
 nvs_get_u8(n,"approved",&approved);nvs_get_u8(n,"critical",&critical);nvs_get_u8(n,"allow_shed",&shed);nvs_get_u8(n,"commissioned",&commissioned);
 nvs_get_u32(n,"min_on_ms",&profile.min_on_ms);nvs_get_u32(n,"min_off_ms",&profile.min_off_ms);
 profile.approved=approved==1;profile.critical=critical!=0;profile.allow_mains_shed=shed==1;
 /* Physical release must be represented by deliberate per-unit commissioning,
    never inferred from compilation or presence of a network credential. */
 #if CONFIG_CARBENTRA_ALLOW_ACTUATION
 state.commissioned=commissioned==1&&profile.approved&&carbentra_meter_calibrated();
 #else
 state.commissioned=false;(void)commissioned;
 #endif
 nvs_close(n);
}
static void sample_append(uint64_t now){
 if(sample_seq==UINT64_MAX){state.commissioned=false;return;}
 if(count==BUFFER_CAP){head=(head+1)%BUFFER_CAP;count--;dropped_telemetry++;}
 carbentra_feedback_status captured_feedback=feedback_status(now);
 sample s={.local_event_seq=local_event_seq,.local_event_ms=local_event_ms,.local_event_result=local_event_result,.manual_hold_until_ms=state.manual_hold_until_ms,.control_mode=carbentra_control_mode(&state,&profile,now),.commissioned=state.commissioned,.maintenance=state.maintenance,.m=measurement,.monotonic_ms=now,.fault_latched=state.fault_latched,.desired_on=state.desired_on,.output_present=captured_feedback==CARBENTRA_FB_AC_PRESENT,.seq=++sample_seq,.feedback_status=captured_feedback,.calibrated=carbentra_meter_calibrated(),.forward_wh=energy_forward_wh,.reverse_wh=energy_reverse_wh,.energy_gaps=energy_gaps,.ram_dropped=dropped_telemetry,.command_dropped=carbentra_network_dropped_commands()};s.feedback_valid=captured_feedback==CARBENTRA_FB_AC_PRESENT||captured_feedback==CARBENTRA_FB_NO_AC_PULSES;
 s.time_trusted=carbentra_network_trusted_time_at(now,&s.lower_s,&s.upper_s);
 buffer[(head+count)%BUFFER_CAP]=s;count++;
}
static void sample_flush(void){
 char epoch[33];uint64_t seq;
 while(carbentra_network_receipt(epoch,&seq)){if(count&&!strcmp(epoch,boot_epoch)&&buffer[head].seq==seq){head=(head+1)%BUFFER_CAP;count--;last_sample_send_ms=0;}}
 if(!count||!carbentra_network_online())return;
 uint64_t now=esp_timer_get_time()/1000;if(last_sample_send_ms&&now-last_sample_send_ms<3000)return;
 sample*s=&buffer[head];
 cJSON*j=cJSON_CreateObject();char seq_text[24];snprintf(seq_text,sizeof(seq_text),"%"PRIu64,s->seq);
 cJSON_AddStringToObject(j,"device_id",state.device_id);cJSON_AddStringToObject(j,"boot_epoch",boot_epoch);cJSON_AddStringToObject(j,"sample_seq",seq_text);cJSON_AddStringToObject(j,"board_revision",CARBENTRA_BOARD_REVISION);cJSON_AddNumberToObject(j,"schema_version",CARBENTRA_WIRE_VERSION);
 cJSON_AddBoolToObject(j,"calibrated",s->calibrated);cJSON_AddBoolToObject(j,"valid",s->m.valid);
 cJSON_AddNumberToObject(j,"monotonic_ms",(double)s->monotonic_ms);cJSON_AddNumberToObject(j,"measurement_monotonic_ms",(double)s->m.sampled_ms);
 cJSON_AddStringToObject(j,"time_quality",s->time_trusted?"authenticated":"unknown");
 if(s->time_trusted){cJSON_AddNumberToObject(j,"unix_s",(double)(s->lower_s+(s->upper_s-s->lower_s)/2));cJSON_AddNumberToObject(j,"unix_lower_s",(double)s->lower_s);cJSON_AddNumberToObject(j,"unix_upper_s",(double)s->upper_s);}
 else{cJSON_AddNullToObject(j,"unix_s");cJSON_AddNullToObject(j,"unix_lower_s");cJSON_AddNullToObject(j,"unix_upper_s");}
 cJSON_AddBoolToObject(j,"fault_latched",s->fault_latched);
 cJSON_AddStringToObject(j,"device_type","smart_plug");cJSON_AddStringToObject(j,"channel_id","relay.1");
 cJSON_AddStringToObject(j,"control_mode",s->control_mode);cJSON_AddBoolToObject(j,"actuation_enabled",s->commissioned);cJSON_AddBoolToObject(j,"maintenance",s->maintenance);
 char local_seq_text[24],local_ms_text[24],hold_text[24];snprintf(local_seq_text,sizeof(local_seq_text),"%"PRIu64,s->local_event_seq);snprintf(local_ms_text,sizeof(local_ms_text),"%"PRIu64,s->local_event_ms);snprintf(hold_text,sizeof(hold_text),"%"PRIu64,s->manual_hold_until_ms);
 cJSON_AddStringToObject(j,"manual_hold_until_uptime_ms",hold_text);
 cJSON *local=cJSON_AddObjectToObject(j,"last_local_input");cJSON_AddNumberToObject(local,"channel",1);cJSON_AddStringToObject(local,"event_seq",local_seq_text);cJSON_AddStringToObject(local,"uptime_ms",local_ms_text);cJSON_AddBoolToObject(local,"pressed",s->local_event_seq!=0);cJSON_AddStringToObject(local,"result",s->local_event_seq?carbentra_result_name(s->local_event_result):"none");
 if(s->m.valid){cJSON_AddNumberToObject(j,"voltage_v",s->m.volts);cJSON_AddNumberToObject(j,"current_a",s->m.amps);cJSON_AddNumberToObject(j,"active_w",s->m.watts);cJSON_AddNumberToObject(j,"reactive_var",s->m.vars);cJSON_AddNumberToObject(j,"apparent_va",s->m.va);cJSON_AddNumberToObject(j,"pf",s->m.pf);cJSON_AddNumberToObject(j,"frequency_hz",s->m.hz);}
 cJSON_AddBoolToObject(j,"board_temperature_valid",s->m.board_temperature_valid);if(s->m.board_temperature_valid)cJSON_AddNumberToObject(j,"board_temperature_c",s->m.board_c);
 cJSON_AddBoolToObject(j,"desired_on",s->desired_on);cJSON_AddBoolToObject(j,"feedback_valid",s->feedback_valid);cJSON_AddBoolToObject(j,"output_present",s->output_present);cJSON_AddStringToObject(j,"output_sensing",carbentra_feedback_name(s->feedback_status));cJSON_AddBoolToObject(j,"voltage_absence_proven",false);
 cJSON_AddNumberToObject(j,"ram_buffer_dropped",s->ram_dropped);cJSON_AddNumberToObject(j,"command_dropped",s->command_dropped);
 cJSON_AddStringToObject(j,"energy_status",s->calibrated?"calibrated_counts_known_intervals_since_boot_not_billing_certified":"uncalibrated_no_energy_result");
 cJSON_AddNumberToObject(j,"known_forward_wh_since_boot",s->forward_wh);cJSON_AddNumberToObject(j,"known_reverse_wh_since_boot",s->reverse_wh);cJSON_AddNumberToObject(j,"energy_uncertain_intervals",s->energy_gaps);
 char*text=cJSON_PrintUnformatted(j);if(text){if(carbentra_network_publish("telemetry",text)>=0){last_sample_send_ms=now;}cJSON_free(text);}cJSON_Delete(j);
 /* Remove only after matching durable edge receipt; retries preserve epoch/sequence. RAM is not power-loss storage. */
}
void app_main(void){
 gpio_config_t out={.pin_bit_mask=(1ULL<<RELAY_GPIO)|(1ULL<<LED_GPIO),.mode=GPIO_MODE_OUTPUT};ESP_ERROR_CHECK(gpio_config(&out));gpio_set_level(RELAY_GPIO,0);gpio_set_level(LED_GPIO,0);
 gpio_config_t inputs={.pin_bit_mask=(1ULL<<BUTTON_GPIO)|(1ULL<<FEEDBACK_GPIO),.mode=GPIO_MODE_INPUT,.pull_up_en=GPIO_PULLUP_ENABLE};ESP_ERROR_CHECK(gpio_config(&inputs));
 carbentra_feedback_init(&feedback_state,esp_timer_get_time(),gpio_get_level(FEEDBACK_GPIO));
 ESP_ERROR_CHECK(gpio_install_isr_service(0));ESP_ERROR_CHECK(gpio_set_intr_type(FEEDBACK_GPIO,GPIO_INTR_ANYEDGE));ESP_ERROR_CHECK(gpio_isr_handler_add(FEEDBACK_GPIO,feedback_edge,NULL));
 uint8_t mac[6];ESP_ERROR_CHECK(esp_read_mac(mac,ESP_MAC_WIFI_STA));snprintf(state.device_id,sizeof(state.device_id),"CM-%02X%02X%02X%02X%02X%02X",mac[0],mac[1],mac[2],mac[3],mac[4],mac[5]);
 uint64_t boots=0;
 journal_ready=carbentra_storage_boot(&journal,&state.last_seq,&boots)==ESP_OK;
 if(!journal_ready)ESP_LOGE(TAG,"NVS journal unavailable; no erase, commissioning or networking");
 snprintf(boot_epoch,sizeof(boot_epoch),"%016"PRIx64"%02x%02x%02x%02x%02x%02x0000",boots,mac[0],mac[1],mac[2],mac[3],mac[4],mac[5]);
 esp_err_t meter_status=carbentra_meter_start();ESP_LOGI(TAG,"Meter startup status: %s",esp_err_to_name(meter_status));load_profile();
 if(!journal_ready)state.commissioned=false;
 if(journal_ready)carbentra_network_start(state.device_id);else ESP_LOGE(TAG,"Journal unavailable; networking disabled");
 uint64_t sample_at=0,publish_at=0,mismatch_since=0;
 carbentra_command pending={0};bool pending_valid=false;uint64_t pending_since=0;uint32_t pending_epoch=0;
 while(1){uint64_t now=esp_timer_get_time()/1000;
  if(now-sample_at>=1000){carbentra_meter_sample(&measurement);
   if(measurement.energy_forward_valid)energy_forward_wh+=measurement.energy_forward_counts*(double)measurement.energy_wh_per_count;
   if(measurement.energy_reverse_valid)energy_reverse_wh+=measurement.energy_reverse_counts*(double)measurement.energy_wh_per_count;
   if(measurement.energy_uncertain||!measurement.valid)energy_gaps++;
   sample_at=now;}
  carbentra_feedback_status fb=feedback_status(now);
  bool feedback_valid=fb==CARBENTRA_FB_AC_PRESENT||fb==CARBENTRA_FB_NO_AC_PULSES;
  bool actual=fb==CARBENTRA_FB_AC_PRESENT;
  bool settled=now>=state.changed_ms&&now-state.changed_ms>=100;
  bool bad=settled&&(fb==CARBENTRA_FB_PRESENT_OR_STUCK_LOW||fb==CARBENTRA_FB_UNKNOWN||(state.desired_on&&!actual)||(!state.desired_on&&actual));
  if(bad){if(!mismatch_since)mismatch_since=now;}else mismatch_since=0;
  bool trip=settled&&(fb==CARBENTRA_FB_PRESENT_OR_STUCK_LOW||(mismatch_since&&now-mismatch_since>1000));
  carbentra_network_tick();int64_t lower=0,upper=0;bool clock_ok=carbentra_network_trusted_time(&lower,&upper);
  /* A new request must not hide an unsettled output mismatch before the
     local latch qualifies. Feedback validity alone is insufficient. */
  carbentra_context x={.online=carbentra_network_online(),.authenticated=carbentra_network_online(),.authorized=true,.clock_trusted=clock_ok,
   .observation_valid=measurement.valid&&feedback_valid&&!bad,.local_trip=trip,.wall_lower_s=lower,.wall_upper_s=upper,.mono_ms=now,.sampled_ms=measurement.sampled_ms};
  /* Authorization derives from mutually authenticated, exact per-device topic
     plus locally commissioned profile; broker ACL deployment remains mandatory. */
  if(carbentra_button_press(&local_button,!gpio_get_level(BUTTON_GPIO),now)){
   carbentra_decision d=carbentra_evaluate_local(&state,&profile,!state.desired_on,&x);
   if(local_event_seq!=UINT64_MAX)local_event_seq++;
   local_event_ms=now;
   if(d.actuate&&!request_relay(d.target_on)){d.status=CARBENTRA_INVALID;d.actuate=false;}
   carbentra_commit_local(&state,&x,d);local_event_result=d.status;sample_append(now);
  }
  carbentra_decision local=carbentra_evaluate(&state,&profile,NULL,&x);
  if(local.latch_fault){bool new_fault=!state.fault_latched;request_relay(false);carbentra_commit(&state,NULL,&x,local);if(new_fault)sample_append(now);}
  carbentra_execution_poll(&execution,now,state.desired_on,state.fault_latched,fb);
  if(execution.needs_publish&&acknowledge(&execution.command,carbentra_execution_name(execution.status),&execution))execution.needs_publish=false;
  if(pending_valid&&(!carbentra_network_online()||pending_epoch!=carbentra_network_epoch()))pending_valid=false;
  if(!pending_valid&&carbentra_network_command(&pending,&pending_epoch)){pending_valid=true;pending_since=now;}
  if(pending_valid&&(!carbentra_network_online()||pending_epoch!=carbentra_network_epoch()))pending_valid=false;
  if(pending_valid){
   carbentra_command command=pending;
   carbentra_decision d=carbentra_evaluate(&state,&profile,&command,&x);
   bool wait_for_lower=d.status==CARBENTRA_BAD_WINDOW&&clock_ok&&command.issued_s>lower&&command.issued_s<=upper&&command.expires_s>upper&&now-pending_since<5000;
   if(wait_for_lower){vTaskDelay(pdMS_TO_TICKS(20));continue;}
   pending_valid=false;
   if(d.status==CARBENTRA_DUPLICATE&&execution.status!=CARBENTRA_EXEC_IDLE&&execution.command.seq==command.seq&&!strcmp(execution.command.id,command.id)){
    acknowledge(&command,carbentra_execution_name(execution.status),&execution);
   }else if(d.status==CARBENTRA_ACCEPTED){
    if(execution.status==CARBENTRA_EXEC_WAITING||execution.needs_publish){acknowledge(&command,"BUSY_AWAITING_FEEDBACK",NULL);}
    else
    if(now-last_accepted_ms<1000){acknowledge(&command,"RATE_LIMIT",NULL);}
    else if(!save_sequence(command.seq)){state.commissioned=false;acknowledge(&command,"PERSISTENCE_FAILURE",NULL);}
    else {
     /* Consume sequence even if physical request fails; retries cannot energize. */
     state.last_seq=command.seq;last_accepted_ms=now;
     if(!carbentra_network_online()||pending_epoch!=carbentra_network_epoch()){acknowledge(&command,"SESSION_CHANGED",NULL);}
     else if(d.actuate&&!request_relay(d.target_on)){acknowledge(&command,"ACTUATION_DISABLED_OR_FAILED",NULL);}
     else{carbentra_commit(&state,&command,&x,d);carbentra_execution_begin(&execution,&command,state.desired_on,now);acknowledge(&command,d.actuate?"REQUESTED_AWAITING_FEEDBACK":"ACCEPTED_NO_CHANGE",&execution);}
    }
   }else acknowledge(&command,carbentra_result_name(d.status),NULL);
  }
  if(now-publish_at>=5000){sample_append(now);publish_at=now;}
  sample_flush();gpio_set_level(LED_GPIO,state.fault_latched?((now/200)%2):carbentra_network_online());
  vTaskDelay(pdMS_TO_TICKS(50));
 }
}

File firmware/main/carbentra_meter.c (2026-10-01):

#include "carbentra_meter.h"
#include "carbentra_meter_decode.h"
#include "carbentra_calibration.h"
#include "carbentra_storage_contract.h"
#include <string.h>
#include <stddef.h>
#include <math.h>
#include "driver/spi_master.h"
#include "driver/gpio.h"
#include "driver/i2c.h"
#include "esp_rom_sys.h"
#include "esp_timer.h"
#include "esp_log.h"
#include "nvs.h"
#include "freertos/FreeRTOS.h"
#include "freertos/task.h"
static spi_device_handle_t meter;
static bool calibrated, i2c_ready;
static uint16_t expected_cs1,expected_cs2;
static float wh_per_count; static uint64_t energy_poll_ms;
static const char*TAG="carbentra_meter";
/* Factory profile, externally calibrated; never filled with made-up gains.
   CRC detects accidental damage, not malicious modification. Secure storage and
   authorized commissioning are independent release requirements. */
static esp_err_t transfer(uint8_t addr,uint16_t *v,bool read){
 uint8_t tx[3]={(uint8_t)(addr|(read?0x80:0)),(uint8_t)(*v>>8),(uint8_t)*v},rx[3]={0};
 spi_transaction_t t={.length=24,.tx_buffer=tx,.rx_buffer=rx};
 gpio_set_level(7,0);esp_err_t e=spi_device_polling_transmit(meter,&t);
 esp_rom_delay_us(5);gpio_set_level(7,1);esp_rom_delay_us(5);
 if(e==ESP_OK&&read) { *v=(uint16_t)((rx[1]<<8)|rx[2]); }
 return e;
}
static esp_err_t read_checked(uint8_t a,uint16_t*v){
 *v=0;esp_err_t e=transfer(a,v,true);if(e!=ESP_OK)return e;
 uint16_t last=0;e=transfer(0x06,&last,true);if(e!=ESP_OK||last!=*v)return ESP_ERR_INVALID_RESPONSE;
 return ESP_OK;
}
static esp_err_t write_checked(uint8_t a,uint16_t v){
 esp_err_t e=transfer(a,&v,false);if(e!=ESP_OK)return e;
 uint16_t last=0;e=transfer(0x06,&last,true);return e==ESP_OK&&last==v?ESP_OK:ESP_ERR_INVALID_RESPONSE;
}
static esp_err_t program_profile(const carbentra_calibration_record*r){
 esp_err_t e=write_checked(0x20,0x5678);if(e!=ESP_OK)return e;
 uint16_t words1[11],words2[10];memcpy(words1,r->calibration,sizeof(words1));memcpy(words2,r->adjustment,sizeof(words2));
 for(int i=0;i<11;i++)if((e=write_checked(0x21+i,words1[i]))!=ESP_OK)return e;
 uint16_t cs1=carbentra_meter_checksum(words1,11),cs2=carbentra_meter_checksum(words2,10),check;
 expected_cs1=cs1;expected_cs2=cs2;
 if((e=write_checked(0x2c,cs1))!=ESP_OK)return e;
 if((e=write_checked(0x30,0x5678))!=ESP_OK)return e;
 for(int i=0;i<10;i++)if((e=write_checked(0x31+i,words2[i]))!=ESP_OK)return e;
 if((e=write_checked(0x3b,cs2))!=ESP_OK)return e;
 if((e=write_checked(0x20,0x8765))!=ESP_OK)return e;
 if((e=write_checked(0x30,0x8765))!=ESP_OK)return e;
 if(read_checked(0x2c,&check)!=ESP_OK||check!=cs1||read_checked(0x3b,&check)!=ESP_OK||check!=cs2)return ESP_ERR_INVALID_CRC;
 if(read_checked(0x01,&check)!=ESP_OK||(check&0xf000))return ESP_ERR_INVALID_STATE;
 return ESP_OK;
}
esp_err_t carbentra_meter_start(void){
 gpio_config_t g={.pin_bit_mask=1ULL<<7,.mode=GPIO_MODE_OUTPUT};ESP_ERROR_CHECK(gpio_config(&g));gpio_set_level(7,1);
 spi_bus_config_t b={.mosi_io_num=6,.miso_io_num=5,.sclk_io_num=4,.quadwp_io_num=-1,.quadhd_io_num=-1,.max_transfer_sz=3};
 esp_err_t e=spi_bus_initialize(SPI2_HOST,&b,SPI_DMA_DISABLED);if(e!=ESP_OK)return e;
 spi_device_interface_config_t d={.clock_speed_hz=100000,.mode=3,.spics_io_num=-1,.queue_size=1};
 if((e=spi_bus_add_device(SPI2_HOST,&d,&meter))!=ESP_OK)return e;
 i2c_config_t ic={.mode=I2C_MODE_MASTER,.sda_io_num=0,.scl_io_num=1,.sda_pullup_en=GPIO_PULLUP_DISABLE,.scl_pullup_en=GPIO_PULLUP_DISABLE,.master.clk_speed=100000};
 if(i2c_param_config(I2C_NUM_0,&ic)==ESP_OK&&i2c_driver_install(I2C_NUM_0,I2C_MODE_MASTER,0,0,0)==ESP_OK)i2c_ready=true;
 /* Reset write may invalidate immediate LastData; follow by reset-state checks. */
 uint16_t reset=0x789a;e=transfer(0,&reset,false);if(e!=ESP_OK)return e;vTaskDelay(pdMS_TO_TICKS(100));
 uint16_t a,bv;if(read_checked(0x20,&a)!=ESP_OK||read_checked(0x30,&bv)!=ESP_OK||a!=0x6886||bv!=0x6886)return ESP_ERR_INVALID_RESPONSE;
 nvs_handle_t n;e=nvs_open(CARBENTRA_NVS_FACTORY,NVS_READONLY,&n);if(e!=ESP_OK)return e;
 carbentra_calibration_record r;size_t size=sizeof(r);e=nvs_get_blob(n,"meter_cal",&r,&size);nvs_close(n);
 if(e!=ESP_OK||!carbentra_calibration_valid(&r,size)){ESP_LOGW(TAG,"No valid per-unit calibration; measurement invalid, no actuation");return ESP_ERR_INVALID_STATE;}
 e=program_profile(&r);calibrated=e==ESP_OK;
 if(calibrated){wh_per_count=100.0f/r.meter_constant_pulses_per_kwh;energy_poll_ms=esp_timer_get_time()/1000;}
 return e;
}
bool carbentra_meter_calibrated(void){return calibrated;}
esp_err_t carbentra_meter_sample(carbentra_measurement*m){
 memset(m,0,sizeof(*m));m->sampled_ms=esp_timer_get_time()/1000;m->energy_uncertain=true;
 if(i2c_ready){uint8_t reg=0,data[2];if(i2c_master_write_read_device(I2C_NUM_0,0x48,&reg,1,data,2,pdMS_TO_TICKS(30))==ESP_OK){int16_t t=(int16_t)((data[0]<<8)|data[1]);m->board_c=(t>>4)*0.0625f;m->board_temperature_valid=true;}}
 if(!calibrated)return ESP_ERR_INVALID_STATE;
 uint16_t u,i,p,q,f,pf,va,status;
 uint16_t cal,adj,cs1,cs2;
 if(read_checked(0x01,&status)!=ESP_OK||read_checked(0x20,&cal)!=ESP_OK||read_checked(0x30,&adj)!=ESP_OK||read_checked(0x2c,&cs1)!=ESP_OK||read_checked(0x3b,&cs2)!=ESP_OK||!carbentra_meter_run_state_ok(cal,adj,cs1,cs2,expected_cs1,expected_cs2,status)){calibrated=false;return ESP_ERR_INVALID_STATE;}
 m->system_status=status;
 if(read_checked(0x49,&u)!=ESP_OK||read_checked(0x48,&i)!=ESP_OK||read_checked(0x4a,&p)!=ESP_OK||read_checked(0x4b,&q)!=ESP_OK||read_checked(0x4c,&f)!=ESP_OK||read_checked(0x4d,&pf)!=ESP_OK||read_checked(0x4f,&va)!=ESP_OK)return ESP_ERR_INVALID_RESPONSE;
 if(u==0xffff||i==0xffff||f==0xffff||pf==0xffff)return ESP_ERR_INVALID_RESPONSE;
 m->volts=u*0.01f;m->amps=i*0.001f;m->watts=carbentra_meter_signed_power(p);m->vars=carbentra_meter_signed_power(q);m->hz=f*0.01f;m->pf=carbentra_meter_power_factor(pf);m->va=va;
 m->valid=isfinite(m->pf)&&fabsf(m->pf)<=1.01f;
 m->energy_interval_ms=m->sampled_ms-energy_poll_ms;m->energy_wh_per_count=wh_per_count;
 /* Both target reads are destructive: exactly one attempt, no target retry.
    An uncertain read creates a reported accounting gap, never an invented zero. */
 m->energy_forward_valid=read_checked(0x40,&m->energy_forward_counts)==ESP_OK;
 m->energy_reverse_valid=read_checked(0x41,&m->energy_reverse_counts)==ESP_OK;
 if(m->energy_interval_ms>5000){m->energy_forward_valid=false;m->energy_reverse_valid=false;}
 m->energy_uncertain=!m->energy_forward_valid||!m->energy_reverse_valid;
 energy_poll_ms=m->sampled_ms;
 return m->valid?ESP_OK:ESP_ERR_INVALID_RESPONSE;
}

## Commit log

2026-09-30 Initialize unified socket engineering scope and acceptance baseline
2026-09-30 Add validated 54-part mechanical assembly and integration checks
    [AntennaCoax.step, AntennaCoax.stl, AntennaFPC.step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]
2026-09-30 Integrate reviewed low-voltage PCB, protection candidates and full assembly
    [CarbonMirror_S16_SystemAssembly.FCStd, CarbonMirror_S16_SystemAssembly.step, bom.csv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]
2026-09-30 Add compiled Rev B endpoint firmware and tested edge reference service
    [partitions.csv]
2026-09-30 Reject conflicting telemetry retries and freeze transmitted sample metadata
2026-09-30 Integrate frozen CARBENTRA Rev B electronics and preserve Rev A visual baseline
    [AntennaCoax.stl, AntennaFPC.stl, AuxFuseBody.stl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]
2026-09-30 feat: freeze Rev B mechanical and electrical engineering review
    [AuxFuseCradle.step, AuxFuseCradle.stl, AuxFuseRetainer.step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]
2026-09-30 refactor: unify project and CARBENTRA branding
    [CARBENTRA-P16-B-base-provisional.FCStd, CARBENTRA-P16-EVT-A.FCStd, CARBENTRA-P16-EVT-A.step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]
2026-10-01 Localize and verify the current CARBENTRA Plug engineering toolchain
    Validated source tree: 828281c98571813db5d4ddcfd2d92c1c9937963d. Preserve prior public main history. Complete delivery/local evolution and original edits remain in local archive and preserve branches.
    [AntennaCoax.stl, AntennaFPC.stl, AuxFuseBody.stl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]
